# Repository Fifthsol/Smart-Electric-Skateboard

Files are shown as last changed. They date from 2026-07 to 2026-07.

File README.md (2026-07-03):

# Smart Electric Skateboard

> **FIRMWARE IS HUMAN REVIEWED, CLAUDE WRITTEN**
> WILL REWRITE BEFORE CREATING FINAL VERSION AND TESTING WITH REAL HARDWARE, DON'T USE FIRMWARE YET.

This is my PCB and CAD design for a smart electric skateboard, I designed it for the most possible modularity and to be as easily assembled as possible

## Key Features

- **XT90-S spark key**: this acts as a physical lock, completing the circuit needed for the board to power on
- **Gyroscope (MPU-6050)**: motion and orientation sensing
- **OLED display**: onboard status readout
- **Buzzer**
- **Wi-Fi + Bluetooth** (via ESP32)
- **GPS logging** (via Arduino Nano to avoid clogging ESP32) — tracks rides for eventual export to Strava
- **Regenerative braking**: logged by the ESP32
- **Hall-effect thumb throttle**: smooth, analog accel/decel control
- **Headlights**: I used a MOFSET gate to control headlights using the ESP32, the headlights are 12V and plenty bright :)

## Design Notes

The PCB is designed for easy assembly and repairability: the ESP32 and Arduino Nano mount use through-hole headers, and most other component connects through screw terminals so you don't have to resolder anything if you want to upgrade a module. A handful of parts (like the XT90 connectors) sit off-board so that wiring is easy to manage. Additionally this board is compatible with basically ever single commercially available ESC, motor, and thumb throttle costing significantly less than other commercially available "smart" skateboards with more configurability.)

You can mount the PCB using countersunk M5 bolts drilled into the main deck of your board. Reference the CAD for the positioning of these holes.

The cover that goes over can be printed and you can use velcro to create a removable cover for all electronics :)

As some of the wiring sits off board, reference my wiring diagram below :) I believe it's pretty self explanatory, use wire splice connectors where there is break points, lay everything out before hand so you cut the appropriate amount of 10 AWG wire.

## Images



here's my final two layer PCB :) you can find the KiCAD file in this repo, when ordering a PCB please only download the final gerber zip (I think I deleted the old one but still be careful)







See full assembly in the Onshape link below!



## CAD

[https://cad.onshape.com/documents/cc961e82541e14a55eb3a3aa/w/93f68d3bf484e10ac8913aa9/e/999f5a267f0d529136fe4578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 ](https://cad.onshape.com/documents/cc961e82541e14a55eb3a3aa/w/93f68d3bf484e10ac8913aa9/e/999f5a267f0d529136fe4578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) - SOURCE FILES, YOU CAN EXPORT, FOR SOME REASON ONSHAPE DOESN'T LET ME LET PUBLIC MAKE COPIES, LMK IF U NEED MORE FILES

I also added the files for the XT90S holder and key I got from thingiverse but you can also get them from the creators' thingiverse links:

https://www.thingiverse.com/thing:3755061 - DSC101
 https://www.thingiverse.com/thing:2323422 - MMANER

Additionally I'd like to credit Linny for the wonderful spark key tutorial:

https://forum.esk8.news/t/how-to-make-a-xt90-loop-key/17664 

## Hardware Recommendations

You can buy any deck you want as long as it has standard skateboard truck mounting holes (don't forget grip tape, I don't want anyone to get a concussion falling off a skateboard at 30mph)

All of the following are compatible with all of the parts:

Here's the kit I recommend: https://diyelectricskateboard.com/products/single-motor-mechanical-kit

Here's the motor I recommend: https://flipsky.net/products/6354-motor?variant=39584732020923 *make sure you buy the 8mm long shaft version, the pinion in the kit is 8mm*

Here's the ESC I recommend: https://www.amazon.com/Flipsky-Electric-Controller-Skateboard-FSESC4-20/dp/B08725X8CT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

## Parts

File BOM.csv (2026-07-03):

Item Name | Qty | Price (total) (USD) | Item link | Notes
Battery 6S 4500mAh 30C LiPo | 1 | $98.99 | https://www.amazon.com/Battery-Softcase-Quadcopter-Airplane-Helicopter/dp/B09CTT8RGG
Charger IMAX B6 LiPo balance charger | 1 | $36.99 | https://www.amazon.com/Battery-Charger-Balance-Discharger-Chargers/dp/B0G64JZ7JV
ESP32 DevKit V1 | 1 | $16.79 | https://www.amazon.com/ESP-WROOM-32-Development-Microcontroller-Integrated-Compatible/dp/B08D5ZD528
Arduino Nano | 1 | $0.00 |  | Already have
NEO-6M GPS module | 1 | $10.99 | https://www.amazon.com/YELUFT-GY-NEO6MV2-Control-Support-Raspberry/dp/B0F2DKWJ4J
MPU-6050 IMU | 1 | $11.79 | https://www.amazon.com/dp/B00LP25V1A
SSD1306 0.96in OLED | 1 | $6.99 | https://www.amazon.com/UCTRONICS-SSD1306-Self-Luminous-Display-Raspberry/dp/B072Q2X2LL
Screw Terminals | 1 | $8.95 | https://www.amazon.com/Tugermoola-Terminal-Connector-Connectors-Terminals/dp/B0D1GSBQWF
WAGO Splicers | 1 | $25.95 | https://www.amazon.com/Connector-Assortment-Splicing-Electrical-Conductors/dp/B0DG5ZK1YS
MicroSD card module + MicroSD card | 1 | $5.99 | https://www.amazon.com/WWZMDiB-Adater-Module-Support-Arduino/dp/B0B779R5TZ
IRLZ44N MOSFET | 1 | $9.99 | https://www.amazon.com/ALLECIN-IRLZ44N-Transistors-IRLZ44NPBF-Mosfets/dp/B0CBKH4XGL | For headlight
3.3V passive buzzer | 1 | $5.99 | https://www.amazon.com/Passive-Resistance-Electronic-Magnetic-Continuous/dp/B0F1KFHSNK
ZUDKSUY hall-effect thumb throttle | 1 | $9.99 | https://www.amazon.com/ZUDKSUY-Electric-Throttle-LeftRight-Replacement/dp/B0D6WB5JRM
Assorted Resistors | 1 | $5.29 | https://www.amazon.com/Avelis-Resistors-Assortment-Precision-Electronic/dp/B0FNRD8B3X
12V LED light bar | 1 | $9.99 | https://www.amazon.com/Lightboss-LED-Light-Off-Road-Waterproof/dp/B09YSWDXSY | For headlight
Solder | 1 | $8.99 | https://www.amazon.com/MAIYUM-63-37-Solder-Electrical-Soldering/dp/B075WB98FJ
Step down buck boost converter | 1 | $7.99 | https://www.amazon.com/Seloky-Converter-Adjustable-Electronic-Stabilizer/dp/B0DBVYP91F
XT90 S | 1 | $12.99 | https://www.amazon.com/FLY-RC-Connector-Anti-Spark-Adapter/dp/B0893CGLP7
Charging Lead | 1 | $8.99 | https://www.amazon.com/FLY-RC-Connector-11-8inch-Silicone/dp/B07C2DGM8D
10 awg wiring black and red | 1 | $14.99 | https://www.amazon.com/Electrical-Extension-Conductors-Flexible-Voltage/dp/B0FFMXVDSC
UBEC | 1 | $11.69 | https://www.amazon.com/ShareGoo-Converter-Module-Quadcopter-Holder/dp/B07DYXTX9H
PCB (2-layer) | 1 | $63.55 |  | Already bought to make Outpost deadline (shipping was most of the cost)
Breakaway header pins 40-pin | 1 | $8.15 | https://www.amazon.com/dp/B01MQ48T2V
Rosin paste flux | 1 | $8.49 | https://www.amazon.com/dp/B008ZIV85A
Hook-and-loop adhesive tape strips | 1 | $4.34 | https://www.amazon.com/dp/B0B58FGF8H
22 AWG hookup wire 6-color kit | 1 | $16.00 | https://www.amazon.com/dp/B07TX6BX47
Total Price (USD): | 440.53

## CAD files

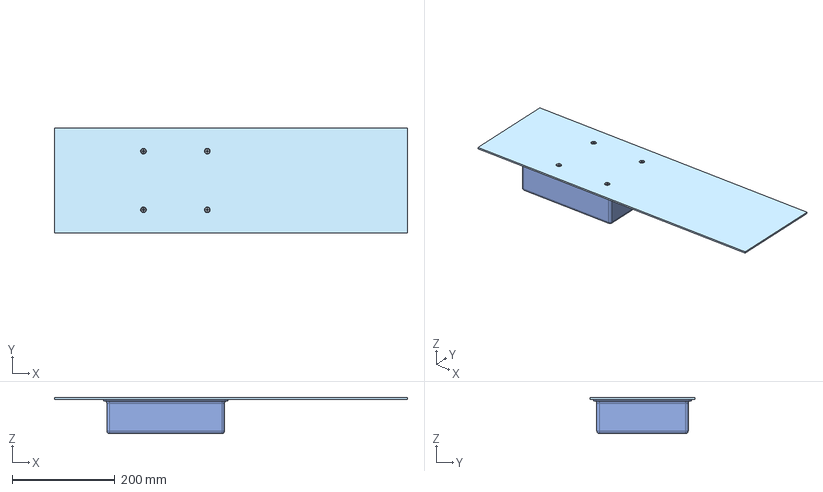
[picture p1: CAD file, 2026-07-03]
CAD/Skateboard Mount Assembly.step
685.8 x 203.2 x 70.4 mm
PH Countersunk flat head screw M5x0.8 x 40 x 4
Hex nut grade A & B M5x0.8 x 4
Electric Skateboard_PCB

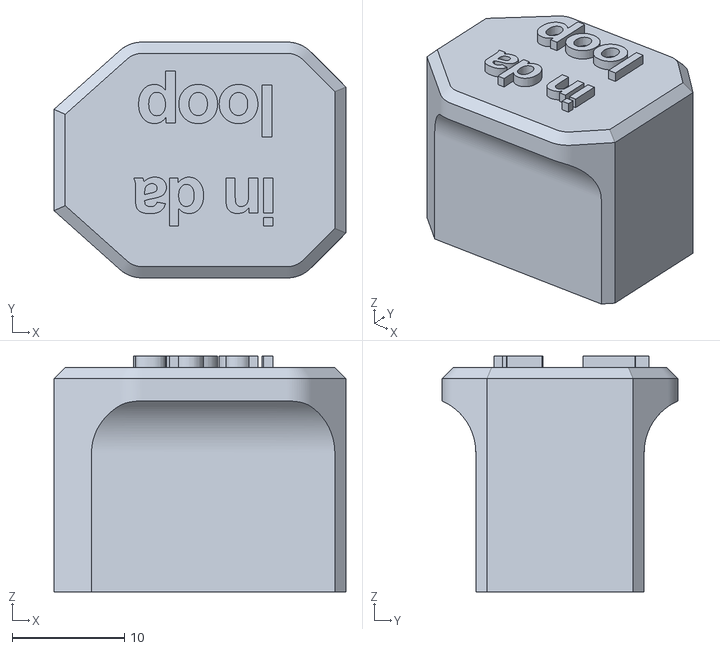
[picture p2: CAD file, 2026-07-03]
CAD/indaloop.stl
26.0 x 21.0 x 21.0

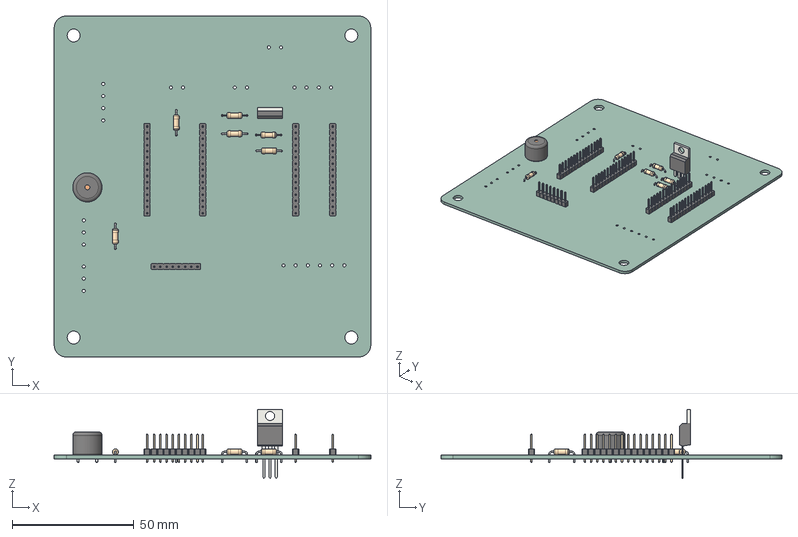
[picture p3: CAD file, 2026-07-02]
PCB/Electric Skateboard.step
130.0 x 140.0 x 28.5 mm
R_Axial_DIN0207_L6.3mm_D2.5mm_P10.16mm_Horizontal x 6
PinHeader_1x15_P2.54mm_Vertical x 4
PinHeader_1x08_P2.54mm_Vertical
TO-220-3_Vertical
Buzzer_12x9.5RM7.6
Electric Skateboard_PCB

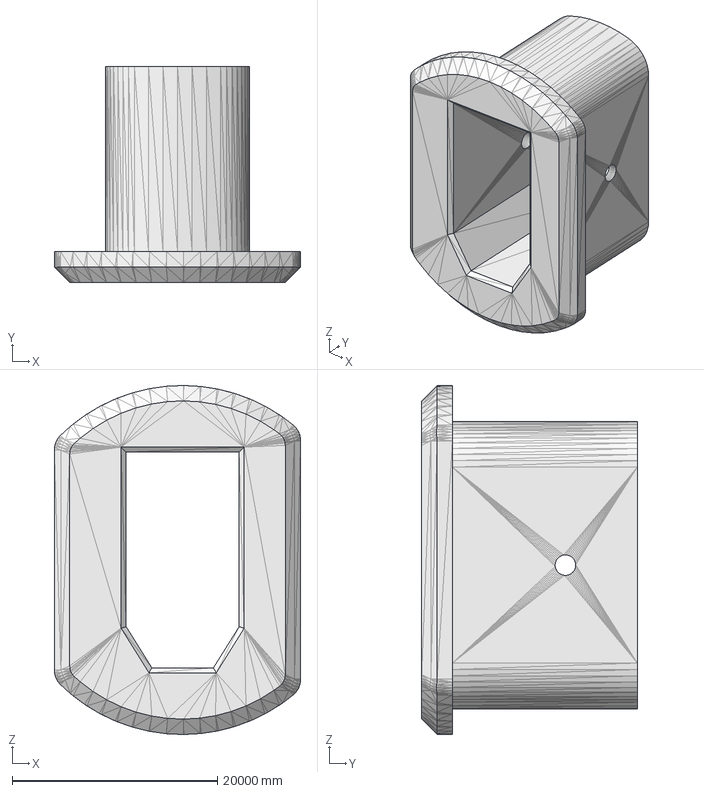
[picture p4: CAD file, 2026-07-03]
CAD/xt-90-s_panel_mount_sm.stp
24000.0 x 21000.0 x 33999.7 mm

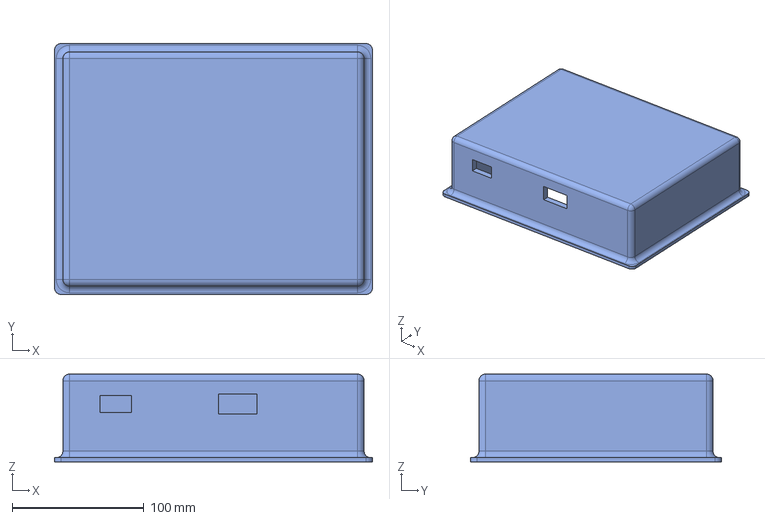
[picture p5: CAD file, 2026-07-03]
CAD/Electric Skateboard Enclosure.step
241.5 x 190.5 x 66.7 mm

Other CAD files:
CAD/xt-90-s_panel_mount_sm.STL

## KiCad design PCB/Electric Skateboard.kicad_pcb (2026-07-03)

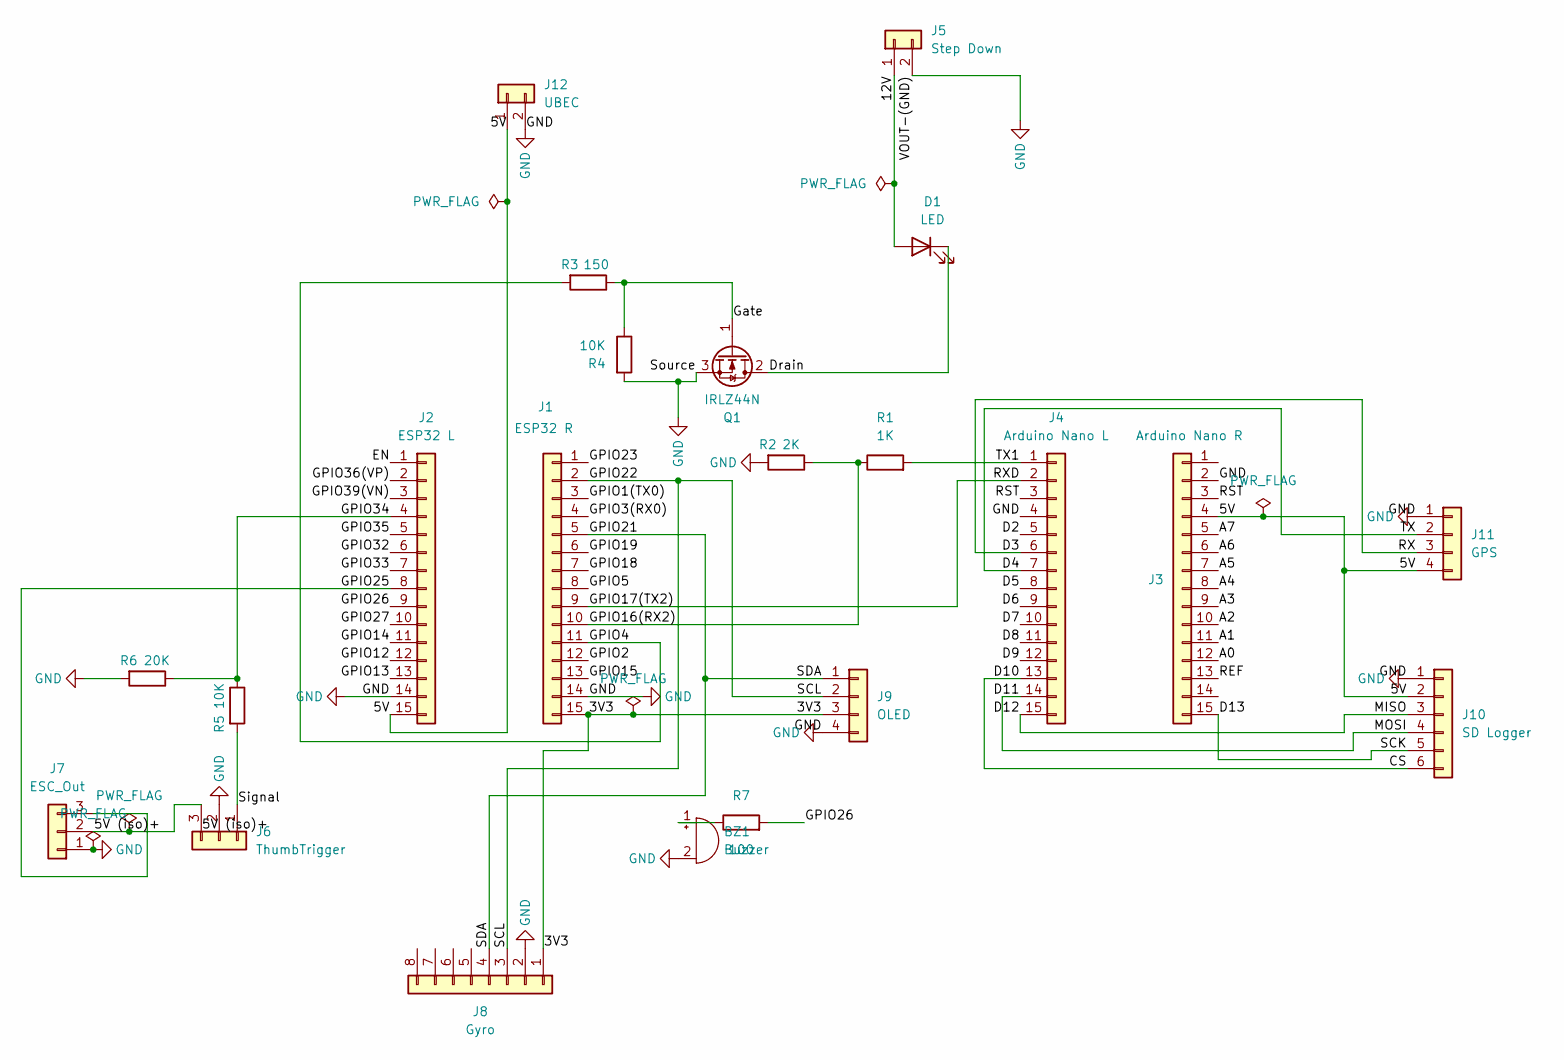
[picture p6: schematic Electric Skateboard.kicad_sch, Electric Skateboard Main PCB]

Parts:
BZ1: Buzzer; Buzzer_12x9.5RM7.6
D1: LED; TerminalBlock_MaiXu_MX126-5.0-02P_1x02_P5.00mm
J1: ESP32 R; PinHeader_1x15_P2.54mm_Vertical
J2: ESP32 L; PinHeader_1x15_P2.54mm_Vertical
J3: Arduino Nano R; PinHeader_1x15_P2.54mm_Vertical
J4: Arduino Nano L; PinHeader_1x15_P2.54mm_Vertical
J5: Step Down; TerminalBlock_MaiXu_MX126-5.0-02P_1x02_P5.00mm
J6: ThumbTrigger; TerminalBlock_MaiXu_MX126-5.0-03P_1x03_P5.00mm
J7: ESC_Out; TerminalBlock_MaiXu_MX126-5.0-03P_1x03_P5.00mm
J8: Gyro; PinHeader_1x08_P2.54mm_Vertical
J9: OLED; TerminalBlock_MaiXu_MX126-5.0-04P_1x04_P5.00mm
J10: SD Logger; TerminalBlock_MaiXu_MX126-5.0-06P_1x06_P5.00mm
J11: GPS; TerminalBlock_MaiXu_MX126-5.0-04P_1x04_P5.00mm
J12: UBEC; TerminalBlock_MaiXu_MX126-5.0-02P_1x02_P5.00mm
Q1: IRLZ44N; TO-220-3_Vertical
R1: 1K; R_Axial_DIN0207_L6.3mm_D2.5mm_P10.16mm_Horizontal
R2: 2K; R_Axial_DIN0207_L6.3mm_D2.5mm_P10.16mm_Horizontal
R3: 150; R_Axial_DIN0207_L6.3mm_D2.5mm_P10.16mm_Horizontal
R4, R5: 10K; R_Axial_DIN0207_L6.3mm_D2.5mm_P10.16mm_Horizontal
R6: 20K; R_Axial_DIN0207_L6.3mm_D2.5mm_P10.16mm_Horizontal
R7: 100; R_Axial_DIN0207_L6.3mm_D2.5mm_P10.16mm_Horizontal

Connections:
/3V3: J1.15, J8.1, J9.3
/5V: J2.15, J3.4, J10.2, J11.4, J12.1
/5V (iso)+: J6.3, J7.2
/12V: D1.2 (A), J5.1
/<NO NET>: J1.1, J3.3, J4.3
/A0: J3.12
/A1: J3.11
/A2: J3.10
/A3: J3.9
/A4: J3.8
/A5: J3.7
/A6: J3.6
/A7: J3.5
/CS: J4.13, J10.6
/D2: J4.5
/D3: J4.6, J11.3
/D4: J4.7, J11.2
/D5: J4.8
/D6: J4.9
/D7: J4.10
/D8: J4.11
/D9: J4.12
/D11: J4.14, J10.4
/D12: J4.15, J10.3
/D13: J3.15, J10.5
/Drain: D1.1 (K), Q1.2 (D)
/EN: J2.1
/GPIO1(TX0): J1.3
/GPIO2: J1.12
/GPIO3(RX0): J1.4
/GPIO4: J1.11, R3.2
/GPIO5: J1.8
/GPIO12: J2.12
/GPIO13: J2.13
/GPIO14: J2.11
/GPIO15: J1.13
/GPIO16(RX2): J1.10, R1.1, R2.1
/GPIO17(TX2): J1.9, J4.2
/GPIO18: J1.7
/GPIO19: J1.6
/GPIO21: J1.5, J8.4, J9.1
/GPIO22: J1.2, J8.3, J9.2
/GPIO25: J2.8, J7.3
/GPIO26: J2.9, R7.2
/GPIO27: J2.10
/GPIO32: J2.6
/GPIO33: J2.7
/GPIO34: J2.4, R5.1, R6.1
/GPIO35: J2.5
/GPIO36(VP): J2.2
/GPIO39(VN): J2.3
/Gate: Q1.1 (G), R3.1, R4.1
/REF: J3.13
/Signal: J6.1, R5.2
/TX1: J4.1, R1.2
GND: BZ1.2 (-), J1.14, J2.14, J3.2, J4.4, J5.2, J6.2, J7.1, J8.2, J9.4, J10.1, J11.1, J12.2, Q1.3 (S), R2.2, R4.2, R6.2
unnamed: BZ1.1 (+), R7.1

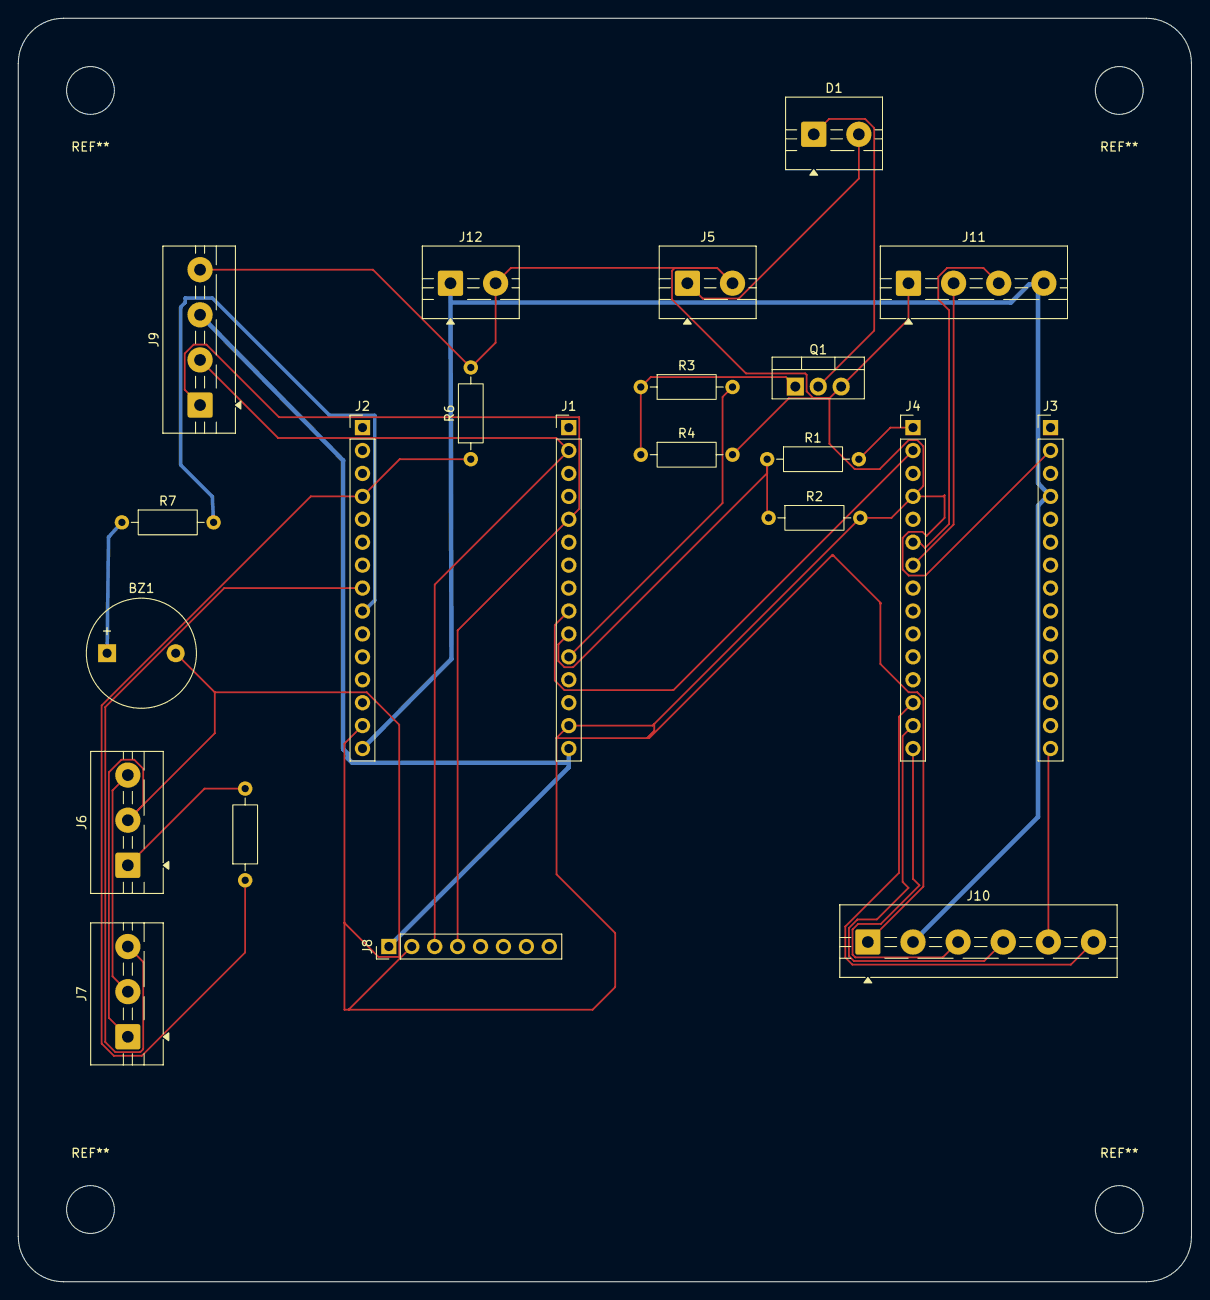
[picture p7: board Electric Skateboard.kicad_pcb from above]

Board: 2 copper layers, 130.0 x 140.0 mm, 22 parts (0 on the bottom side), 25 nets.

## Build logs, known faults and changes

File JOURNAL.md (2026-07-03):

# 6/29/26 - 8 Hours

## Day 1 of Designing, Part Choice, Wiring Diagram, and Rough CAD, 6/29/26
BTW I'm finalizing this journal a day late because I got sidetracked and forgot to commit it yesterday. Oops!

So before starting this project I had a very lofty idea on what I wanted to build and to be honest didn't understand the X tier project idea pool (sorry Alex), so I dreamed up my
lofty goal of a smart electric skateboard and sent it in slack with my hopes and dreams. Without accounting for the fact that... I actually need to design it before getting almost 1K in funding! I'm still not quite sure on how I'm going to finance this thing especially because I don't feel like it qualifies for X tier, S at most I feel... Regardless we move forward.

So, in order to punch my ticket to Outpost in approximately 9 days..... let's go

### Part Choices

I wanted to do this project because I had a spare RC car motor and ESC lying around that I figured out how to use with a NiMH battery pack. I thought that if I tweaked the gear ratio enough I could get enough power out of a measly 9.6V battery to fully flesh out an electric skateboard... Sadly I was wrong.

In order to make a smart electric skateboard you first have to have an electric skateboard (duh). So I started out with the deck. I realized that I actually wanted to be able to bring this thing places so I chose a relatively small base deck which can just be upgraded to a better one need be. A $40 27 x 8 longboard deck. Nothing terribly remarkable but should have enough space for all my electronics. 

Next up, was the drive train kit, which is essentially the belt and pulley system that mounts a motor to the axle of the skateboard. I found a simple one on diyelectricskateboard.org (a little bit on the nose, you think?) It comes with wheels, trucks, etc. etc. The assembled kit is pictured below.



As much as I'd love to buy the motor from the website I couldn't find a good ESC-Motor combination for cheap, so I looked on flipsky and ended up finding a good motor ESC combo with the "Mini FSESC4.2 50A" VESC and the "BLDC Belt Motor 6354 190KV" motor (I'll include links to all of the parts I'm planning to buy below). From there finding most of the other parts was was easy because the features I wanted came quite easily once you add an ESP32 and Arduino Nano to an electric skateboard architecture.

The features I wanted to add are:

- Bluetooth control (ESP32)
- An app that connects to the board and lets you post your rides on **Strava** (the most important feature for me)
- GPS Datalogging
- Headlights
- Hall effect throttle
- Spark key that unlocks the entire system by completing the circuit
- OLED Screen 
- Gyroscope

So I chose all of the parts relatively quickly as a lot of them are just standard ESP32/Arduino components.

This was stuff like the ESP32 kit, NEO6M GPS module, MPU-6050, SSD1306 OLED, on off switch, MicroSD module, buzzer, etc. etc.

However, something that became a bit of a pain was wiring all of these parts together, in particularly the hall effect thumb throttle I found on amazon and the LED light bar.

Since the battery I chose is a 6S 22.2V 5000mAH lipo I had to use a voltage step down module and added a UBEC to make sure the voltage is properly regulated as it flows to the ESP32, Arduino Nano, and the headlights.

These headlights ended up also being a pain. I found a 7 inch set on Amazon that is usually used for cars, I thought wiring it would be easy turns out it isn't because there isn't a signal wire on it and only the voltage and ground.

This is where I introduce my excellently formatted wiring diagram...


As you see here I added a MOFSET gate pin to ensure that I could turn off and on the headlights. Additionally, I had to put a lot of effort in making sure everything shares a common ground and that the Arduino Nano doesn't fry the ESP32; the ESP32 accepts only 3.3V input from signal pins and the Nano outputs 5V. Same thing occured with the hall effect thumb trigger.

A neat thing that I discovered while designign this wiring chart was the usage of a "spark key". When I was looking into all the different RC lipo battery connectors (which there's a LOT of), I decided to use exclusively the XT90-S, the S is for the extra resistor in the female housing that prevents current overflow, so when I was looking at documentation I stumbled upon an old forum post on how to set up a XT90 "loop key" Which is essentially an XT90 connector that completes the circuuit of a board as the on and off switch (I'm actually considering removing the toggle switch begause of the existence of this solution).

Below is an image of a loop key and a link to the tutorial.

https://forum.esk8.news/t/how-to-make-a-xt90-loop-key/17664 



Tommorow, I plan on finalizing this wiring diagram in a software that isn't google drawings so I can actually design the mounting board that will go on the skateboard.

Oh I also did make a rough CAD of the case but I decided against using this specific design because of A) how annoying it'd be to print and B) I realized that I can just mount the electronics board to the skateboard with some really strong velcro adhesive.

Here's a picture of my old design which uses a bunch of 10-32 bolts and holes drilled into the skateboard itself.



You can see the slot for the XT90 spark key and the three holes for the motor wires that run from the ESC to the motor as well as the slot for the OLED display and a weird hole I thought I would use for the battery?!

The battery solution was another reason I switched to using a velcro mounted fixture because I wanted to switch the battery easily without it being too much of a pain. I realized that I could use velcro when I was thinking of how my FRC team (6423 represent!) mounted the acrylic panel that shielded the brain pan and how strong that velcro was. I don't have a photo but trust me it was really strong and none of our electrical system was damaged during the season. :))

Anyways thats all I did today, it took a long time....

Here's my BOM too:

## Drivetrain

| Item | Link | Price |
|---|---|---|
| Drive Train Kit | [Link](https://diyelectricskateboard.com/products/single-motor-mechanical-kit) | $250 |
| Motor — 6355 190KV Brushless Outrunner | [Link](https://flipsky.net/products/6354-motor?variant=39584732020923) | $71 |
| ESC — Flipsky Mini FSESC4.20 50A | [Link](https://flipsky.net/products/mini-fsesc4-20-50a-with-anodized-heat-sink) | $56 |
| Battery — 6S 5000mAh 30C LiPo | [Link](https://www.amazon.com/OVONIC-Battery-5000mAh-Airplane-Helicopter/dp/B0CP5KHH46) | $95 |
| Charger — IMAX B6 LiPo Balance Charger | [Link](https://www.amazon.com/Battery-Charger-Balance-Discharger-Chargers/dp/B0G64JZ7JV) | $35 |
| Deck & Enclosure — Blank Longboard Deck | [Link](https://www.amazon.com/Blank-Graphic-Longboard-Deck-CRUISER/dp/B004H2SP5Y) | $35 |

## Electronics

| Item | Link | Price |
|---|---|---|
| Switch | — | — |
| ESP32 DevKit V1 | [Link](https://www.amazon.com/ESP-WROOM-32-Development-Microcontroller-Integrated-Compatible/dp/B08D5ZD528) | $17 |
| Arduino Nano | *already have* | — |
| NEO-6M GPS Module | [Link](https://www.amazon.com/YELUFT-GY-NEO6MV2-Control-Support-Raspberry/dp/B0F2DKWJ4J) | $11 |
| MPU-6050 IMU | [Link](https://www.amazon.com/dp/B00LP25V1A) | $12 |
| SSD1306 0.96" OLED | [Link](https://www.amazon.com/UCTRONICS-SSD1306-Self-Luminous-Display-Raspberry/dp/B072Q2X2LL) | $14 |
| On/Off Rocker Switch | [Link](https://www.amazon.com/DIYables-Rocker-Arduino-ESP8266-Raspberry/dp/B0CN8VRSRF) | — |
| MicroSD Card Module + Card | [Link](https://www.amazon.com/WWZMDiB-Adater-Module-Support-Arduino/dp/B0B779R5TZ) | $6 |
| IRLZ44N MOSFET (headlight) | [Link](https://www.amazon.com/ALLECIN-IRLZ44N-Transistors-IRLZ44NPBF-Mosfets/dp/B0CBKH4XGL) | $10 |
| 3.3V Passive Buzzer | [Link](https://www.amazon.com/Passive-Buzzer-Piezoelectric-Arduino-Raspberry/dp/B0DHGP95K4) | $7 |
| 4x4 Membrane Keypad | [Link](https://www.amazon.com/DIYmalls-Keypad-Membrane-Keyboard-Arduino/dp/B086Z1ZXNJ) | $8 |
| ZUDKSUY Hall-Effect Thumb Throttle | [Link](https://www.amazon.com/ZUDKSUY-Electric-Throttle-LeftRight-Replacement/dp/B0D6WB5JRM) | $10 |
| Assorted Resistors | [Link](https://www.amazon.com/Avelis-Resistors-Assortment-Precision-Electronic/dp/B0FNRD8B3X) | $5 |
| 12V LED Light Bar (headlight) | [Link](https://www.amazon.com/Lightboss-LED-Light-Off-Road-Waterproof/dp/B09YSWDXSY) | $9 |
| Hookup Wire Assortment | [Link](https://www.amazon.com/s?k=breadboard+jumper+wire+assortment) | $7 |
| Heat Shrink Tubing | [Link](https://www.amazon.com/Ginsco-580-pcs-Assorted-Sleeving/dp/B01MFA3OFA) | $8 |
| Solder | [Link](https://www.amazon.com/MAIYUM-63-37-Solder-Electrical-Soldering/dp/B075WB98FJ) | $9 |
| Grip Tape | [Link](https://www.amazon.com/Black-Diamond-Longboard-Skateboard-Sheet/dp/B0013T1NZS) | $12 |
| Step Down Buck/Boost Converter | [Link](https://www.amazon.com/Seloky-Converter-Adjustable-Electronic-Stabilizer/dp/B0DBVYP91F) | $6 |
| XT90-S Connectors *(need wired versions)* | [Link](https://www.amazon.com/FLY-RC-Connector-Anti-Spark-Adapter/dp/B0893CGLP7) | $13 |
| 12 AWG Wire (black & red) | — | — |
| UBEC | [Link](https://www.amazon.com/ShareGoo-Converter-Module-Quadcopter-Holder/dp/B07DYXTX9H) | $19 |
| Charging Lead | [Link](https://www.amazon.com/FLY-RC-Connector-11-8inch-Silicone/dp/B07C2DGM8D) | — |
| Dupont Connectors + Crimpers | — | — |

**Estimated subtotal (listed prices):** ~$729 

I'm probably going to cut the keypad and the toggle switch btw, they seemed kind of useless ICL.

Logging off!

# 6/30/26 - 3 Hours

## Wiring Reformatting

Ok so... I may have messed up the resistor values but I managed to fix them by looking at a lot of datasheets for MOFSET gates and documentation on how I should connnect an Arduino Nano to an ESP32 (you have to use them because arduino outputs 5v and esp32 only takes 3.3)

However, I fixed them and here is my final rewire, nothing too different from the old sheet but I'm quite happy about how clean this one looks :)



A little embarrassed how long this took cause its my first time using Draw.io (I was also very distracted by the World Cup my family was watching in the background) but hopefully tommorow I'll be making the circuit board. Peace!

## 7/1/26 - 4 Hours

Alrighty, today I turned my wiring diagrams into an actual, real schematic!

Here's the final product before I got into the process that went into it and what I had to change and stuff :)



Sorry if the image is super low res I dont know how to properly export it from KiCAD.

Anyways, most of my time was basically spent rethinking the way that I'm connecting all these modules to the arduino to finalize the wiring.

I also did a very aggressive recheck of each place where resistors are needed and all of their nodes.

When designing this board I had to think about how I would integrate this circuitboard with the physical XT90 connector system that you can see in the ohter wiring diagram. I realized that I could basically take the wires of the ESC, UBEC, step down, and headlights, and screw them into wire terminals on the board which made things extremely easy to work with.

From there it was just a lot a lot of checking and reviewing part diagrams for modules (I'm so scared of accidently using a component that can't handle 5V, but like 99% of arduino modules take 3.3V-5V so I really shouldn't be worrying)
I also made my own Arduino Nano and ESP32 schematics from two 15x1 connector schematics so I could ensure each pin was correctly labeled. 

The next part was turning it into a PCB but I think I'm going to call it a day because I already chose all of the footprints (they're mostly through hole and screw terminals so assembly is extremely easy) so I'm going to delay it to tommorow. I am tired!!!!

I'm also going to do a final wiring/compatibility check before finalizing the PCB and figuring out the layout.

Then I need to worry about the case ;-; I'm really tied but I know I can put the work into finishing this design soon :3

Oh yeah, I used used screw terminals for the GPS and SD logger because I want to ziptie them to a specific part of the case (so I can easily take out the SD and put the GPS antenna in an optimal position) instead of having them tied to the PCB.

I hope to finish this PCB or a rough form of it tmmrw and get the case done as well so I can send in my S/X tier pitch. Then I'm going to order all of the parts and do a test wire with each module individually to ensure they all function and that I know how to program them.

From there I'll finalize my case design and tweak the PCB again to get my desired build which hopefully will be quick :))))))

I think I should also do a quick macropad to make sure I can at least bring *something* to Outpost if I can't finish in time (I think that's how it works?)

## 7/2/26 - 5 Hours

Currently contemplating my life choices because my motor won't get here by the time I have to submit...

Welp I finished my PCB and CAD at least

Heres what my mounting solution is going to be for the pcb



Essentially I'm going to countersink M5 holes into the skateboard deck and 3D print spacers so I can put my PCB on it while velcroing a bunch of other components down to the main body of the deck (basically everything that isn't on the PCB that I don't want to be locked in placed)

To protect this I also modeld a shield which will be velcroed onto the main deck. Seen here:



I cut out holes to glue on the XT90S spark key hole which I found a free 3D model for on thingiverse: 
https://www.thingiverse.com/thing:2323422/comments 

basically you can just slot it into the holes and superglue down the edges which is dandy :)



Additionally I finally figured out how to finalize my PCB



Isn't that a beauty. You can find the gerber zip in the KiCad folder of this repo. :)

That's pretty much the project design finished. Thanks for your time and I hope to update this journal againwhen I finish building the super duper awesome board.

I don't know if my motor will come in time for the 7/7 deadline so I might not be done by then and wow PCB shipping is expensive ;-; so I hope to at least have a working development board for this project before the deadline.

I also had to figure out the resistor values so that my thumb trigger which has signal running at 5V doesn't fry my ESP32.

I would send a more polished BOM but realistically I have no clue on what I'm going to have done before the deadline for Outpost so I'll post that update when we cross that mountain (or hill? but it feels more like a mountain).

Gahaha I need to type for one more minute before I can post a devlog lol :() I'm staring this hackatime timer down very intensely

# 7/2/26 - 3 Hours

Another 3 hours hahahaa.......

I found out that my PCB would fry the ESP32 because I made the nets for the 3v3 and 5v
merged by accident.

This was an easy fix though I just seperated the nets to use both the upper and lower copper layers so here is the finalized product:



What a beauty amiright.

I also added a bunch of stuff to the BOM, made my orders, and got ready to make my project for rereview.

Thanks for reading :).

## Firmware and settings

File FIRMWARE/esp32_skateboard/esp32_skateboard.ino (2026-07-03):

#include <Wire.h>
#include <ESP32Servo.h>
#include <Adafruit_GFX.h>
#include <Adafruit_SSD1306.h>
#include <Adafruit_MPU6050.h>
#include <BLEDevice.h>
#include <BLEServer.h>
#include <BLEUtils.h>
#include <BLE2902.h>

// ------------------------- Pins -------------------------
constexpr int PIN_ESC       = 25;   // PPM out to Mini FSESC4.20
constexpr int PIN_THROTTLE  = 34;   // ADC1_CH6, input-only
constexpr int PIN_HEADLIGHT = 4;    // MOSFET gate
constexpr int PIN_SDA       = 21;
constexpr int PIN_SCL       = 22;
constexpr int PIN_NANO_RX   = 16;   // Serial2 RX  <- Nano TX
constexpr int PIN_NANO_TX   = 17;   // Serial2 TX  -> Nano RX

// ------------------------- Tuning -------------------------
// Raw ADC counts from the hall throttle AFTER the 10K/20K divider.
// 0.8V rest / 4.2V full on the sensor becomes ~0.53V / ~2.8V at the pin.
// Run once with DEBUG_THROTTLE=true, note your real min/max, put them here.
constexpr bool  DEBUG_THROTTLE   = false;
constexpr int   THR_RAW_MIN      = 700;    // raw ADC at rest      (CALIBRATE!)
constexpr int   THR_RAW_MAX      = 3300;   // raw ADC at full pull (CALIBRATE!)
constexpr int   THR_DEADBAND     = 60;     // counts of slop above rest

constexpr int   ESC_MIN_US       = 1500;   // neutral (VESC "current, no reverse")
constexpr int   ESC_MAX_US       = 2000;   // full throttle
constexpr int   ESC_NEUTRAL_US   = 1500;
// Soft-start: max microseconds of throttle change per 20ms control tick.
constexpr int   ESC_SLEW_US      = 12;

// Safety
constexpr float TILT_CUTOFF_DEG    = 65.0;  // board this far over = you fell off
constexpr uint32_t THROTTLE_TIMEOUT_MS = 250; // bad ADC / wire pull -> neutral

// ------------------------- BLE UUIDs -------------------------
#define SVC_UUID   "6e400001-b5a3-f393-e0a9-e50e24dcca9e" // NUS-style
#define RX_UUID    "6e400002-b5a3-f393-e0a9-e50e24dcca9e" // app -> board
#define TX_UUID    "6e400003-b5a3-f393-e0a9-e50e24dcca9e" // board -> app (notify)

// ------------------------- Globals -------------------------
Servo esc;
Adafruit_SSD1306 oled(128, 64, &Wire, -1);
Adafruit_MPU6050 mpu;
bool oledOK = false, mpuOK = false;

BLECharacteristic* bleTx = nullptr;
volatile bool bleConnected = false;

// State
bool  armed      = false;   // must be armed (app or auto) before ESC responds
bool  headlight  = false;
bool  logging    = false;   // Nano SD logging state (echoed back by Nano)
int   escNowUs   = ESC_NEUTRAL_US;
float tiltDeg    = 0;
uint32_t lastControlTick = 0;
uint32_t lastTelemetry   = 0;
uint32_t lastOled        = 0;

// GPS data streamed up from the Nano:  $FIX,lat,lon,kmh,alt,sats,hhmmss
struct GpsData {
  bool   valid = false;
  double lat = 0, lon = 0;
  float  kmh = 0, alt = 0;
  int    sats = 0;
  char   timeStr[10] = "--:--:--";
  uint32_t lastRx = 0;
} gps;

char nanoLine[96];
size_t nanoLen = 0;

// ------------------------- BLE callbacks -------------------------
class ServerCB : public BLEServerCallbacks {
  void onConnect(BLEServer*) override    { bleConnected = true; }
  void onDisconnect(BLEServer* s) override {
    bleConnected = false;
    // Failsafe: rider's phone dropped mid-command? Coast to neutral.
    s->getAdvertising()->start();
  }
};

void handleCommand(const String& cmd);

class RxCB : public BLECharacteristicCallbacks {
  void onWrite(BLECharacteristic* c) override {
    String v = String(c->getValue().c_str());
    v.trim();
    if (v.length()) handleCommand(v);
  }
};

// ------------------------- Setup -------------------------
void setup() {
  Serial.begin(115200);                                  // USB debug
  Serial2.begin(9600, SERIAL_8N1, PIN_NANO_RX, PIN_NANO_TX); // Nano link

  pinMode(PIN_HEADLIGHT, OUTPUT);
  digitalWrite(PIN_HEADLIGHT, LOW);

  analogReadResolution(12);
  analogSetPinAttenuation(PIN_THROTTLE, ADC_11db);       // full 0-3.3V range

  // ESC: standard 50Hz servo signal. VESC must be configured for PPM
  // ("App Settings -> PPM -> Current No Reverse") in VESC Tool.
  esc.setPeriodHertz(50);
  esc.attach(PIN_ESC, 1000, 2000);
  esc.writeMicroseconds(ESC_NEUTRAL_US);

  Wire.begin(PIN_SDA, PIN_SCL);
  oledOK = oled.begin(SSD1306_SWITCHCAPVCC, 0x3C);
  if (oledOK) {
    oled.clearDisplay();
    oled.setTextColor(SSD1306_WHITE);
    oled.setTextSize(2);
    oled.setCursor(10, 24);
    oled.print("SK8 BOOT");
    oled.display();
  }
  mpuOK = mpu.begin(0x68);
  if (mpuOK) {
    mpu.setAccelerometerRange(MPU6050_RANGE_8_G);
    mpu.setGyroRange(MPU6050_RANGE_500_DEG);
    mpu.setFilterBandwidth(MPU6050_BAND_21_HZ);
  }

  // BLE
  BLEDevice::init("SmartSk8");
  BLEServer* srv = BLEDevice::createServer();
  srv->setCallbacks(new ServerCB());
  BLEService* svc = srv->createService(SVC_UUID);
  bleTx = svc->createCharacteristic(TX_UUID, BLECharacteristic::PROPERTY_NOTIFY);
  bleTx->addDescriptor(new BLE2902());
  BLECharacteristic* rx =
      svc->createCharacteristic(RX_UUID, BLECharacteristic::PROPERTY_WRITE);
  rx->setCallbacks(new RxCB());
  svc->start();
  BLEAdvertising* adv = BLEDevice::getAdvertising();
  adv->addServiceUUID(SVC_UUID);
  adv->setScanResponse(true);
  adv->start();

  Serial.println(F("[ESP32] Smart skateboard up. Waiting for ARM."));
}

// ------------------------- Command handler -------------------------
// App -> board commands (also usable from the Arduino Serial monitor
// via USB for bench testing — type them into Serial):
//   ARM / DISARM        enable-disable the ESC output
//   LIGHT ON|OFF|TOGGLE headlight MOSFET
//   LOG START|STOP      SD ride logging on the Nano (GPX for Strava)
//   PING                replies PONG
void handleCommand(const String& cmd) {
  String c = cmd; c.toUpperCase();
  if      (c == "ARM")          { armed = true;  beepAck(); }
  else if (c == "DISARM")       { armed = false; escNowUs = ESC_NEUTRAL_US; }
  else if (c == "LIGHT ON")     { headlight = true; }
  else if (c == "LIGHT OFF")    { headlight = false; }
  else if (c == "LIGHT TOGGLE") { headlight = !headlight; }
  else if (c == "LOG START")    { Serial2.println(F("$LOG,1")); }
  else if (c == "LOG STOP")     { Serial2.println(F("$LOG,0")); }
  else if (c == "PING")         { bleNotify("PONG"); }
  digitalWrite(PIN_HEADLIGHT, headlight ? HIGH : LOW);
  Serial.print(F("[CMD] ")); Serial.println(c);
}

void bleNotify(const String& s) {
  if (bleConnected && bleTx) {
    bleTx->setValue(s.c_str());
    bleTx->notify();
  }
}

// NOTE: the buzzer on this PCB rev is wired straight across 3V3 and GND
// (BZ1 pads: 3V3 / GND — no GPIO net), so firmware can't actually drive it.
// This is a stub so the call sites are ready when you bodge it to a GPIO.
void beepAck() { /* wire BZ1 to a free GPIO (e.g. 26/27) to enable */ }

// ------------------------- Nano serial parsing -------------------------
void pollNano() {
  while (Serial2.available()) {
    char ch = (char)Serial2.read();
    if (ch == '\n' || ch == '\r') {
      if (nanoLen) { nanoLine[nanoLen] = 0; parseNanoLine(nanoLine); nanoLen = 0; }
    } else if (nanoLen < sizeof(nanoLine) - 1) {
      nanoLine[nanoLen++] = ch;
    } else nanoLen = 0; // overflow, resync
  }
}

void parseNanoLine(char* line) {
  // $FIX,lat,lon,kmh,alt,sats,hh:mm:ss   |   $NOFIX,sats   |   $LOGACK,0|1
  if (!strncmp(line, "$FIX,", 5)) {
    char* p = line + 5;
    char* tok[6]; int n = 0;
    for (char* t = strtok(p, ","); t && n < 6; t = strtok(nullptr, ",")) tok[n++] = t;
    if (n == 6) {
      gps.lat = atof(tok[0]); gps.lon = atof(tok[1]);
      gps.kmh = atof(tok[2]); gps.alt = atof(tok[3]);
      gps.sats = atoi(tok[4]);
      strncpy(gps.timeStr, tok[5], sizeof(gps.timeStr) - 1);
      gps.valid = true; gps.lastRx = millis();
    }
  } else if (!strncmp(line, "$NOFIX", 6)) {
    gps.valid = false; gps.lastRx = millis();
    char* c = strchr(line, ','); if (c) gps.sats = atoi(c + 1);
  } else if (!strncmp(line, "$LOGACK,", 8)) {
    logging = (line[8] == '1');
    bleNotify(logging ? "LOGGING ON" : "LOGGING OFF");
  }
}

// ------------------------- Control loop pieces -------------------------
int readThrottleUs() {
  // Median-of-3 to knock down ADC noise
  int a = analogRead(PIN_THROTTLE);
  int b = analogRead(PIN_THROTTLE);
  int c = analogRead(PIN_THROTTLE);
  int raw = max(min(a, b), min(max(a, b), c));

  if (DEBUG_THROTTLE) { Serial.print(F("thr raw=")); Serial.println(raw); }

  raw = constrain(raw, THR_RAW_MIN, THR_RAW_MAX);
  if (raw < THR_RAW_MIN + THR_DEADBAND) return ESC_NEUTRAL_US;
  return map(raw, THR_RAW_MIN + THR_DEADBAND, THR_RAW_MAX, ESC_MIN_US, ESC_MAX_US);
}

void updateTilt() {
  if (!mpuOK) return;
  sensors_event_t a, g, t;
  mpu.getEvent(&a, &g, &t);
  // Roll relative to gravity — big number means board is on its side/upside-down
  float ax = a.acceleration.x, ay = a.acceleration.y, az = a.acceleration.z;
  tiltDeg = degrees(acos(constrain(az / sqrt(ax*ax + ay*ay + az*az), -1.0f, 1.0f)));
}

void controlTick() {
  updateTilt();

  int target = ESC_NEUTRAL_US;
  bool tiltFault = mpuOK && (tiltDeg > TILT_CUTOFF_DEG);

  if (armed && !tiltFault) target = readThrottleUs();
  if (tiltFault && armed) { armed = false; bleNotify("TILT CUTOFF"); }

  // Slew limit for a soft launch (down = instant, up = ramped)
  if (target > escNowUs)      escNowUs = min(target, escNowUs + ESC_SLEW_US);
  else                        escNowUs = target;

  esc.writeMicroseconds(escNowUs);
}

// ------------------------- OLED + telemetry -------------------------
void drawOled() {
  if (!oledOK) return;
  oled.clearDisplay();
  oled.setTextSize(3);
  oled.setCursor(0, 0);
  if (gps.valid) { oled.print((int)gps.kmh); oled.setTextSize(2); oled.print(F("km/h")); }
  else           { oled.setTextSize(2); oled.print(F("NO GPS")); }

  oled.setTextSize(1);
  oled.setCursor(0, 32);
  oled.print(F("SAT:")); oled.print(gps.sats);
  oled.print(F("  ")); oled.print(gps.timeStr);

  oled.setCursor(0, 44);
  oled.print(armed ? F("[ARMED]") : F("[SAFE ]"));
  oled.print(headlight ? F(" LIGHT") : F("      "));
  oled.print(logging ? F(" REC")   : F("    "));

  oled.setCursor(0, 56);
  oled.print(F("BLE:")); oled.print(bleConnected ? F("OK ") : F("-- "));
  oled.print(F("THR:")); oled.print(escNowUs);
  oled.display();
}

void sendTelemetry() {
  // Board -> app, one CSV line per second:
  // T,<armed>,<light>,<log>,<kmh>,<lat>,<lon>,<sats>,<tilt>,<escUs>
  char buf[120];
  snprintf(buf, sizeof(buf), "T,%d,%d,%d,%.1f,%.6f,%.6f,%d,%.0f,%d",
           armed, headlight, logging, gps.kmh, gps.lat, gps.lon,
           gps.sats, tiltDeg, escNowUs);
  bleNotify(buf);
}

// ------------------------- Main loop -------------------------
void loop() {
  uint32_t now = millis();

  pollNano();

  // Allow bench commands over USB serial too
  if (Serial.available()) {
    String s = Serial.readStringUntil('\n');
    s.trim(); if (s.length()) handleCommand(s);
  }

  if (now - lastControlTick >= 20) {        // 50 Hz control loop
    lastControlTick = now;
    controlTick();
  }
  if (now - lastOled >= 250) { lastOled = now; drawOled(); }
  if (now - lastTelemetry >= 1000) { lastTelemetry = now; sendTelemetry(); }

  // GPS link watchdog
  if (gps.valid && now - gps.lastRx > 5000) gps.valid = false;
}

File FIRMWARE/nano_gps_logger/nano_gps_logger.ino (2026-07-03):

#include <SoftwareSerial.h>
#include <TinyGPSPlus.h>
#include <SPI.h>
#include <SD.h>

constexpr uint8_t PIN_GPS_RX = 4;   // Nano listens here (GPS TX)
constexpr uint8_t PIN_GPS_TX = 3;   // Nano talks here   (GPS RX)
constexpr uint8_t PIN_SD_CS  = 10;

constexpr uint32_t GPS_BAUD  = 9600;   // NEO-6M default
constexpr uint32_t LINK_BAUD = 9600;   // to ESP32 (keep modest for SoftwareSerial coexistence)
constexpr uint32_t FIX_PERIOD_MS = 1000;

SoftwareSerial gpsSerial(PIN_GPS_RX, PIN_GPS_TX);
TinyGPSPlus gps;

bool sdOK = false;
bool logging = false;
File gpxFile;
char gpxName[13];          // 8.3 filename e.g. RIDE07.GPX
uint32_t lastFixSent = 0;
uint32_t lastLogged  = 0;

char cmdBuf[16];
uint8_t cmdLen = 0;

// ---------------------------------------------------------
void setup() {
  Serial.begin(LINK_BAUD);       // hardware UART -> ESP32
  gpsSerial.begin(GPS_BAUD);

  sdOK = SD.begin(PIN_SD_CS);
  Serial.println(sdOK ? F("$SD,1") : F("$SD,0"));
}

// ---------------------------------------------------------
void loop() {
  // Feed the NMEA parser
  while (gpsSerial.available()) gps.encode(gpsSerial.read());

  // Commands from the ESP32: $LOG,1  /  $LOG,0
  while (Serial.available()) {
    char ch = (char)Serial.read();
    if (ch == '\n' || ch == '\r') {
      if (cmdLen) { cmdBuf[cmdLen] = 0; handleCmd(); cmdLen = 0; }
    } else if (cmdLen < sizeof(cmdBuf) - 1) {
      cmdBuf[cmdLen++] = ch;
    } else cmdLen = 0;
  }

  uint32_t now = millis();
  if (now - lastFixSent >= FIX_PERIOD_MS) {
    lastFixSent = now;
    sendFix();
    if (logging && gps.location.isValid()) logTrackpoint();
  }
}

// ---------------------------------------------------------
void handleCmd() {
  if (!strncmp(cmdBuf, "$LOG,1", 6)) startLog();
  else if (!strncmp(cmdBuf, "$LOG,0", 6)) stopLog();
}

// ---------------------------------------------------------
void sendFix() {
  if (gps.location.isValid() && gps.location.age() < 3000) {
    // $FIX,lat,lon,kmh,alt,sats,hh:mm:ss
    Serial.print(F("$FIX,"));
    Serial.print(gps.location.lat(), 6); Serial.print(',');
    Serial.print(gps.location.lng(), 6); Serial.print(',');
    Serial.print(gps.speed.kmph(), 1);   Serial.print(',');
    Serial.print(gps.altitude.meters(), 1); Serial.print(',');
    Serial.print(gps.satellites.value()); Serial.print(',');
    printTime2(gps.time.hour());   Serial.print(':');
    printTime2(gps.time.minute()); Serial.print(':');
    printTime2(gps.time.second());
    Serial.println();
  } else {
    Serial.print(F("$NOFIX,"));
    Serial.println(gps.satellites.value());
  }
}

void printTime2(uint8_t v) {
  if (v < 10) Serial.print('0');
  Serial.print(v);
}

// ---------------------------------------------------------
void startLog() {
  if (logging || !sdOK) { ack(); return; }
  // Find a free RIDE##.GPX slot
  for (uint8_t i = 0; i < 100; i++) {
    snprintf(gpxName, sizeof(gpxName), "RIDE%02u.GPX", i);
    if (!SD.exists(gpxName)) break;
  }
  gpxFile = SD.open(gpxName, FILE_WRITE);
  if (gpxFile) {
    gpxFile.println(F("<?xml version=\"1.0\" encoding=\"UTF-8\"?>"));
    gpxFile.println(F("<gpx version=\"1.1\" creator=\"SmartSk8\" xmlns=\"http://www.topografix.com/GPX/1/1\">"));
    gpxFile.println(F("<trk><name>Skateboard Ride</name><trkseg>"));
    gpxFile.flush();
    logging = true;
  }
  ack();
}

void stopLog() {
  if (logging && gpxFile) {
    gpxFile.println(F("</trkseg></trk></gpx>"));
    gpxFile.close();
  }
  logging = false;
  ack();
}

void ack() {
  Serial.print(F("$LOGACK,"));
  Serial.println(logging ? '1' : '0');
}

// ---------------------------------------------------------
void logTrackpoint() {
  if (!gpxFile) return;
  // <trkpt lat=".." lon=".."><ele>..</ele><time>YYYY-MM-DDTHH:MM:SSZ</time></trkpt>
  gpxFile.print(F("<trkpt lat=\""));
  gpxFile.print(gps.location.lat(), 6);
  gpxFile.print(F("\" lon=\""));
  gpxFile.print(gps.location.lng(), 6);
  gpxFile.print(F("\"><ele>"));
  gpxFile.print(gps.altitude.meters(), 1);
  gpxFile.print(F("</ele>"));

  if (gps.date.isValid() && gps.time.isValid()) {
    char ts[24];
    snprintf(ts, sizeof(ts), "<time>%04u-%02u-%02uT%02u:%02u:%02uZ</time>",
             gps.date.year(), gps.date.month(), gps.date.day(),
             gps.time.hour(), gps.time.minute(), gps.time.second());
    gpxFile.print(ts);
  }
  gpxFile.println(F("</trkpt>"));

  // Flush every ~5s so a battery pull doesn't eat the ride
  if (millis() - lastLogged > 5000) { gpxFile.flush(); lastLogged = millis(); }
}

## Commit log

2026-07-02 Added KiCad Project
    [Electric Skateboard.kicad_pcb, Electric Skateboard.kicad_sch]
2026-07-02 Added Fillet
    [Electric Skateboard.kicad_pcb]
2026-07-02 Ran DRC on PCB
    [Electric Skateboard.kicad_pcb]
2026-07-02 7/2/26 - 5 Hours
    [Electric Skateboard Case.stl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]
2026-07-02 Hall Effect Trigger Implementation
2026-07-03 Changed File Organization, Added BOM
    [Electric Skateboard Case.stl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]
2026-07-03 Re Review Fixes
    [BOM.csv.csv, Electric Skateboard Case.stl, Electric Skateboard Enclosure.step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]
2026-07-03 CSV Fix
    [BOM.csv]
2026-07-03 BOM Change
    [BOM.csv]
2026-07-03 Fixed PCB
    [Electric Skateboard.kicad_pcb]
2026-07-03 Updated BOM, Fixed PCB for final order
    [BOM.csv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]
2026-07-03 updated BOM
    [BOM.csv]
2026-07-03 BOM Update
    [BOM.csv]
2026-07-03 Updated ReadMe, Added to BOM
    [BOM.csv, indaloop.stl, xt-90-s_panel_mount_sm.STL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]
2026-07-03 Fix README formatting and update CAD link
    Updated project title formatting and modified CAD link with additional context.
2026-07-03 Enhance CAD section with formatted link
    Updated the CAD section with a clickable link for source files and improved formatting.
2026-07-03 Added Drl files to Gerber
    [Electric Skateboard.kicad_pcb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]
2026-07-03 Modify PCB entry in BOM with shipping cost note
    Updated PCB description to include shipping cost details.
    [BOM.csv]
2026-07-03 Added wires to BOM
    [BOM.csv]
